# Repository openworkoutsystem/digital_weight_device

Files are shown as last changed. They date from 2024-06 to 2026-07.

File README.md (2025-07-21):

# Project Overview: Open-Source Smart Fitness

Open Workout System is an open-source community creating a high-fidelity smart health/fitness device dedicated to improving your fitness and health. Our primary goal is to develop cost-conscious, accessible, and safe workout systems that cater to a broad audience, from general fitness enthusiasts to individuals undergoing physical therapy. By leveraging open-source principles, we aim to foster a community of developers, fitness professionals, and users who can collaborate to continually improve and expand our solutions.

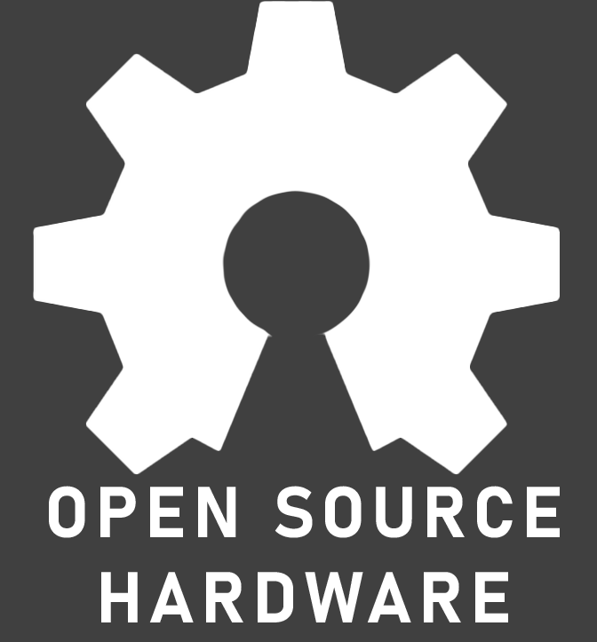
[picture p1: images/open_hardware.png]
Open Source Hardware

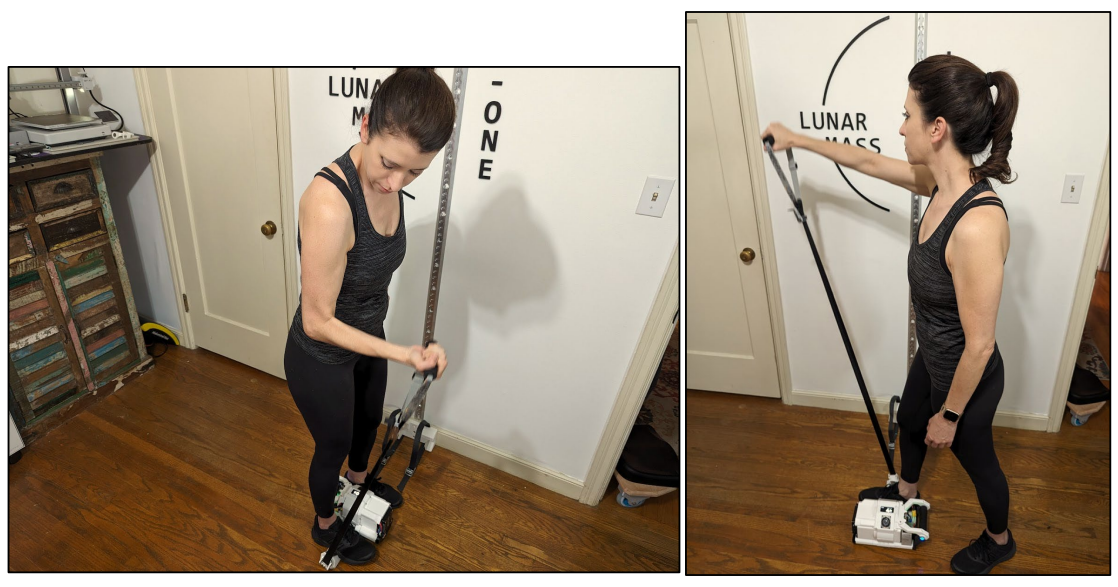
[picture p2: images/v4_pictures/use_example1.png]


### V4 Design Readme --> [V4 Design Readme](README_V4DESIGN.md)

### What's Different About This Project/Fitness Solution?

- Completely open source
- 11 lb device that can emulate up to 200 lb (exact specs in design)
- Fully wireless
- Use it anywhere: on the floor, with a door, wall, etc.
- Measures everything you want: power, speed, rep counter, timing
- Benchmarks your fitness
- Tracks your physical therapy progress
- Physical therapists will be able to design and monitor your progress for recovery (remotely and locally)
- Gamify your workout: We're excited to see how this device will be integrated in fun new ways to enhance your routine.

The ultra-compact BLDC motor-driven workout system is our core design focus, aimed at providing a comprehensive, safe, and affordable fitness solution. Traditional workout systems can be intimidating due to their size, complexity, and cost. Our system is ultra-compact and easy to use, ensuring it fits seamlessly into your life. The body-friendly strap enhances safety over a traditional cable system.

### Why Open Source?

As an open-source project, we believe in the power of community and collaboration. By making our designs, code, and documentation freely available, we enable others to contribute to the project, helping to accelerate innovation and bring high-quality fitness solutions to more people. Our commitment to open source ensures transparency, adaptability, and continuous improvement.

Hardware is hard. We want to provide access to a fantastic and safe fitness device for others to build their creative ideas on! Our philosophy is that we make you better, you make us better, and we're all better for it. We know, like us, there are others with great ideas on how to improve their daily routines and unique needs.

### Contribution

We welcome contributions to our project! Whether it's code, hardware designs, documentation, or testing, your input is valuable. To get started please join our Discord Community --> [Open Workout System Discord Server](https://discord.gg/DzmPTt3dUt)
For more information, questions, or collaboration inquiries, please contact us at [aaron.willey+ows@gmail.com].

### Safety and Accessibility

Safety is paramount in our design philosophy. Our Digital Weight Workout System includes features such as device movement sensing, dropped handle detection, and programmable safety limits to ensure a safe workout experience. The lower cost of entry allows a wider audience to access this advanced technology, promoting health and fitness across various demographics. Our goal is to provide a safer and more effective alternative to traditional free weights, reducing the risk of injury and making fitness accessible to all.

## Outline of Project Repositories

- **Digital Weight Device**: The main fitness device central to this project.
- **Applications that communicate with the digital weight**:
  - Web app (simple PWA interface for testing)
  - Mobile app - coming soon
  - Watch app - coming soon
- **Remote device**: Smart controller/remote for the digital weight.
- **Game demos**: Example integration of the device with different games for exploration of use ideas.

### Device Highlights

- **11 lb device**
- **Strength training up to 200 lb (400 lb 2X)**
- **Adaptive rowing and paddling modes**
- **Simple controls (mechanical and touch)**
- **Fully wireless**
- **Self-charging modes**
- **No installation required**
- **Safety features**:
  - Body-friendly strap (no cables)
  - Device movement sensing
  - Dropped handle detection
  - Programmable safety limits
  - Resistance only operation mode

### License

This project is licensed under the terms of the MIT license. See the [LICENSE](LICENSE) file for details.

## Digital Weight Workout System

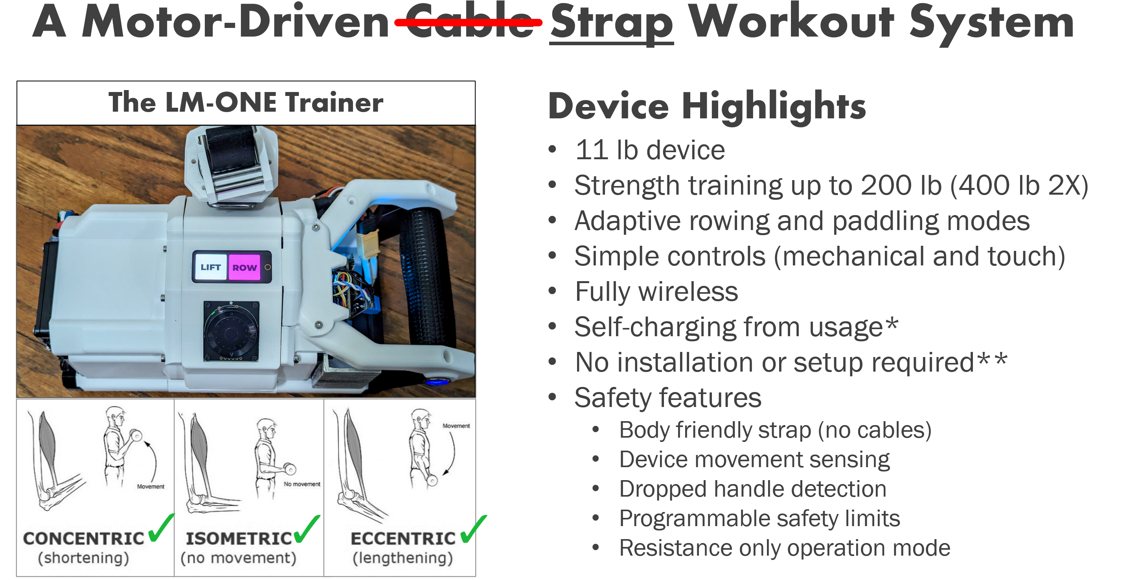
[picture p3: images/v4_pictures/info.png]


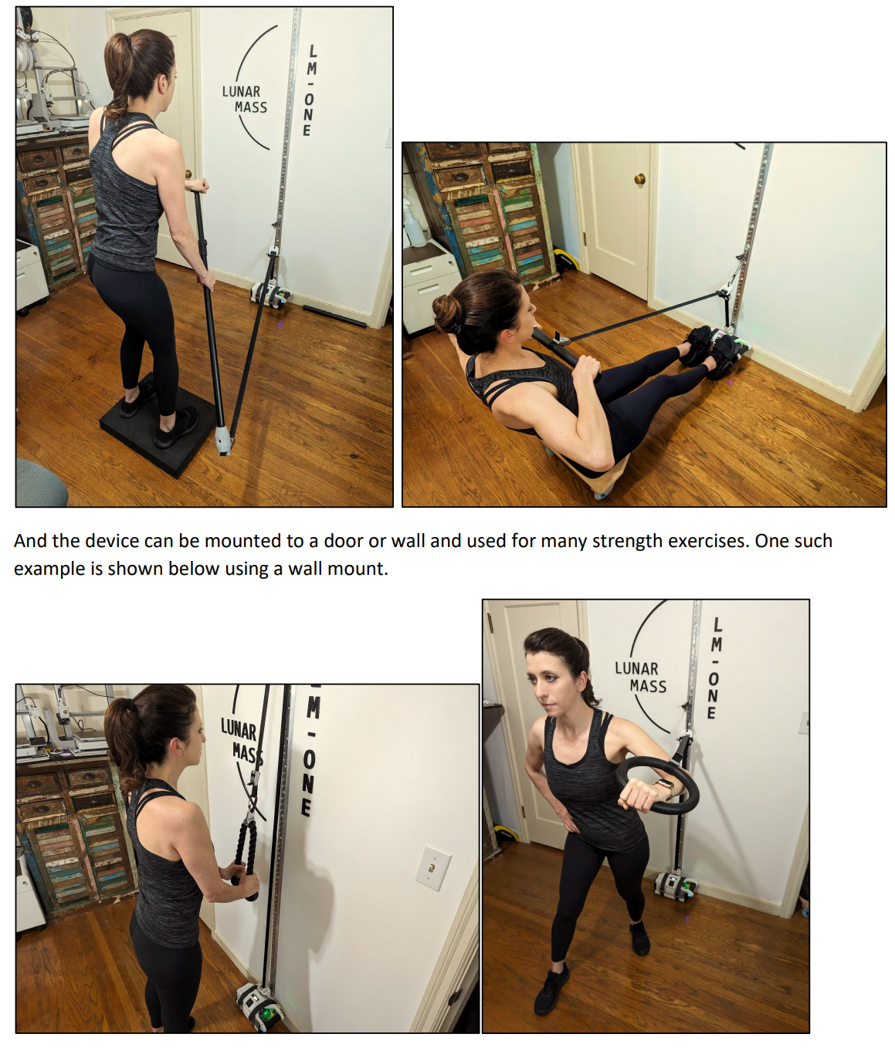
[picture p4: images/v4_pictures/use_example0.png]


Open Source Hardware

### Images and Features

#### v4 Pictures

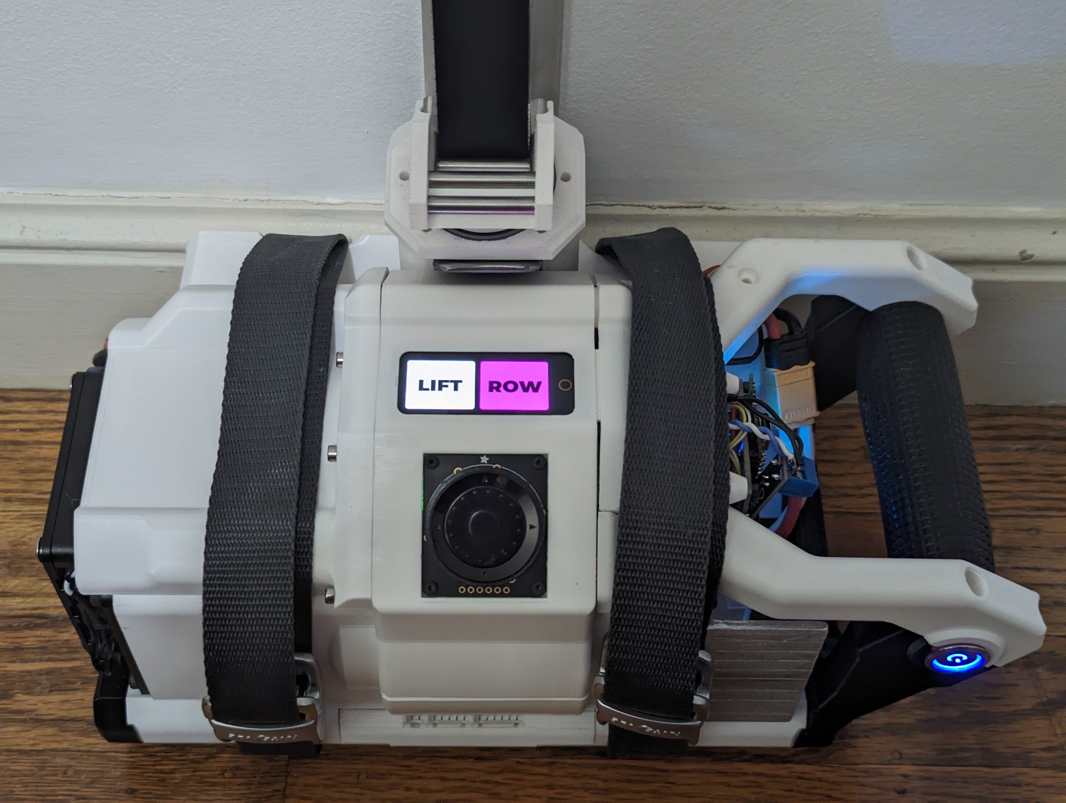
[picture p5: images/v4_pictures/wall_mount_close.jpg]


Open Source Hardware

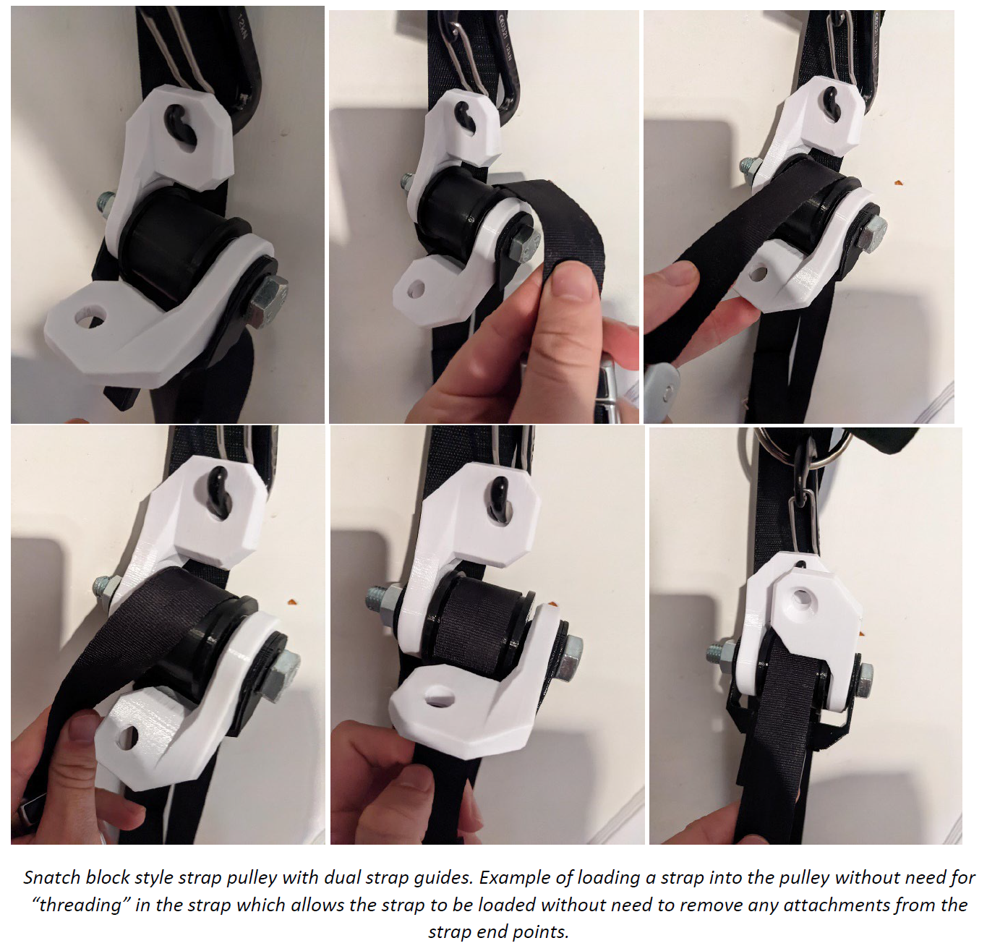
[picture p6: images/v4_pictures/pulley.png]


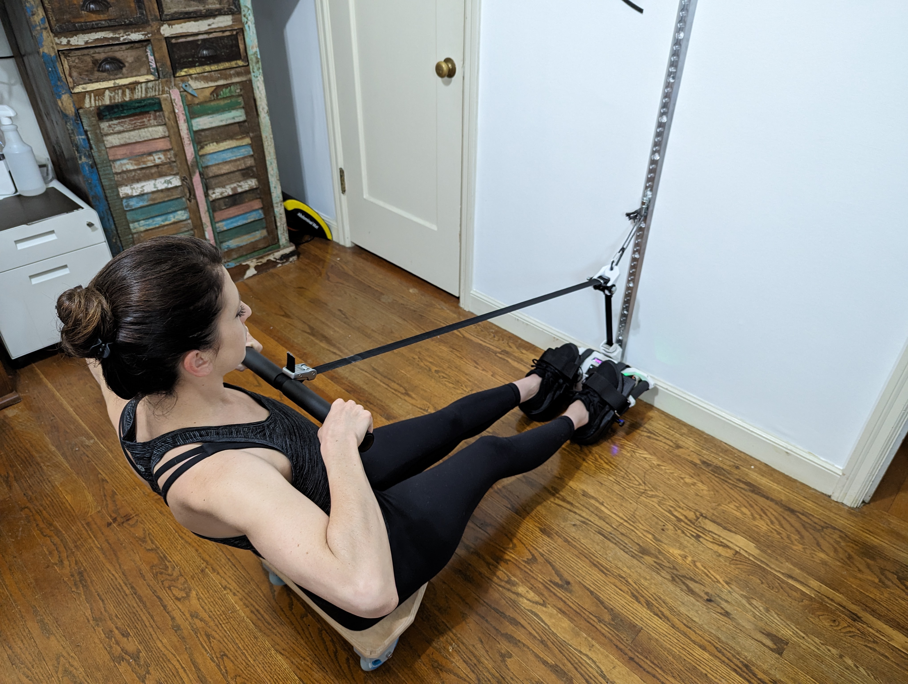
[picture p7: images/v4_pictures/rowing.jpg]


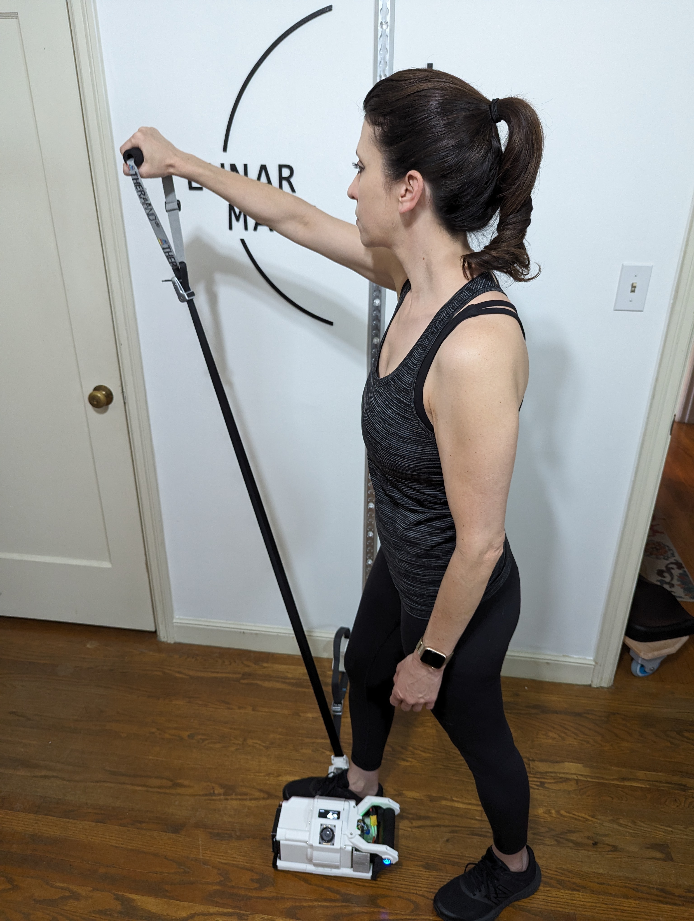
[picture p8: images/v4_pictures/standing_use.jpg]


Open Source Hardware

<!-- - ![Rowing](images/v4_pictures/rowing.jpg)
- ![Standing Use](images/v4_pictures/standing_use.jpg)
- ![Pulley](images/v4_pictures/pulley.png)
- ![Strength Tricep](images/v4_pictures/strength_tricep.jpg)
- ![Wall Mount Close](images/v4_pictures/wall_mount_close.jpg)
- ![Angle](images/v4_pictures/angle.jpg) -->

## Older v1_v2_v3 Pictures

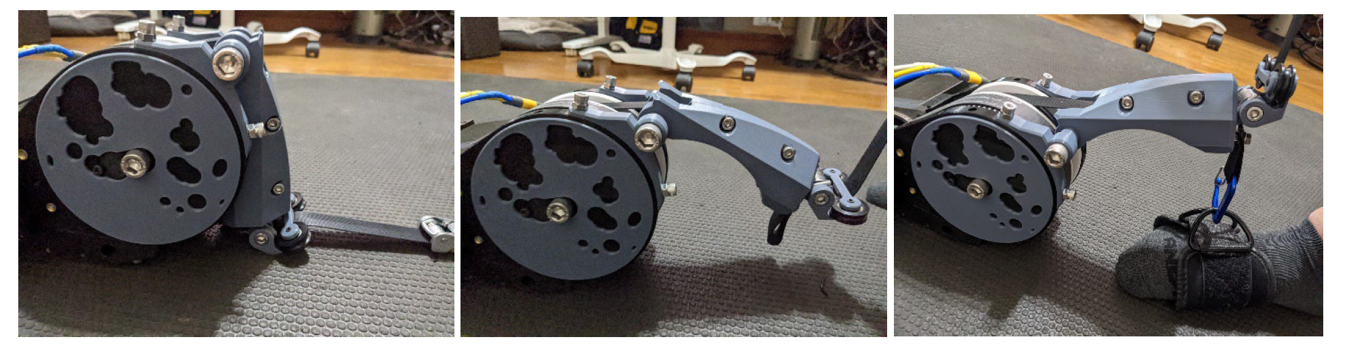
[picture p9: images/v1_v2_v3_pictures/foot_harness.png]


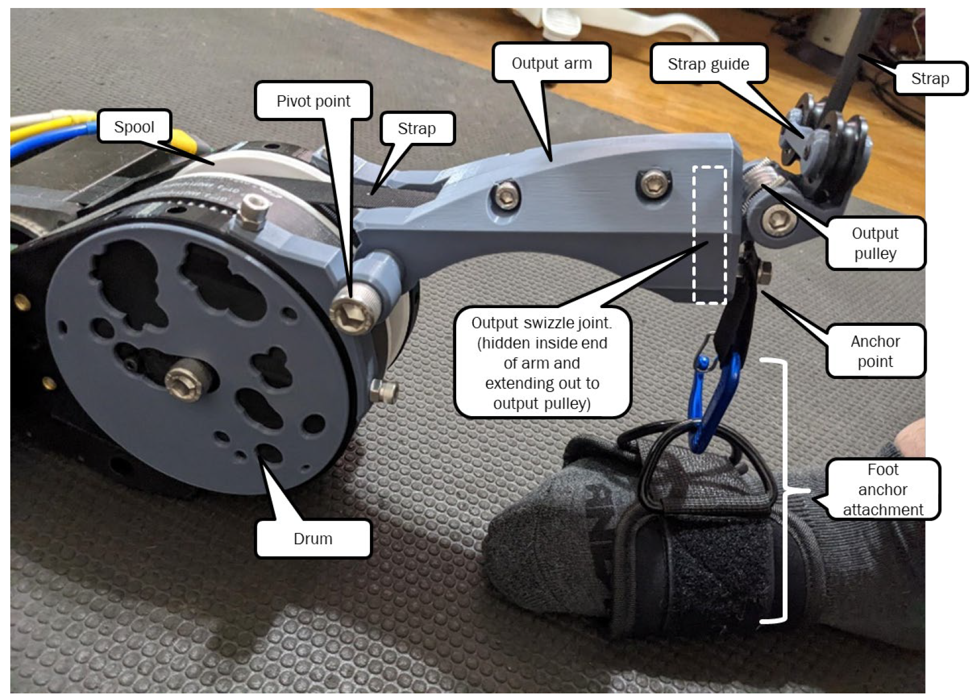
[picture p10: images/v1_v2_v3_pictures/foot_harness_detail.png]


<!-- - ![Foot Harness](images/v1_v2_v3_pictures/foot_harness.png)
- ![Detail](images/v1_v2_v3_pictures/foot_harness_detail.png) -->

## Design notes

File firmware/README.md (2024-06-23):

# Digital Weight Latest FW for V4

## Release Date

June 2024, as demonstrated at open sauce SF

## Overview

Two separate esp32 controllers. One as the master state machine for the device. The other only serves as a control input from the screen and controller knob.

## Odrive compiled firmware to be added

Note I have received soft confirmation from ODrive team that it is likely possible for us to obtain the source firmware and PCB files from their team. This could allow us to branch and create a cost optimized controller for our application and possibly directly use the odrive mcu for some of our higher-level control functions

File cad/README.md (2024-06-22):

# Digital Weight: V4 CAD

## Release Date

June 2024, as demonstrated at open sauce SF

## Introduction

CAD files to build V4

## Software and tools

- Autodesk inventor and Fusion 360
- Prusa MK3s
- Bambulab A1 (not mini)

## V4 Known Issues and Limitations - CAD related

- **Thermal Management**: Both motors tend to heat up too quickly, indicating a potential thermal issue.
- **Maintenance Challenges**:
  - Difficulty in removing motors with controllers for calibration.
  - Painful removal process for the handle when maintaining the odrive s1 controller.
- **Wiring**: Wire congestion around the device leads to pinched wires, reducing load carrying capacity.

## V4 Image Preview

V4 Render Angle
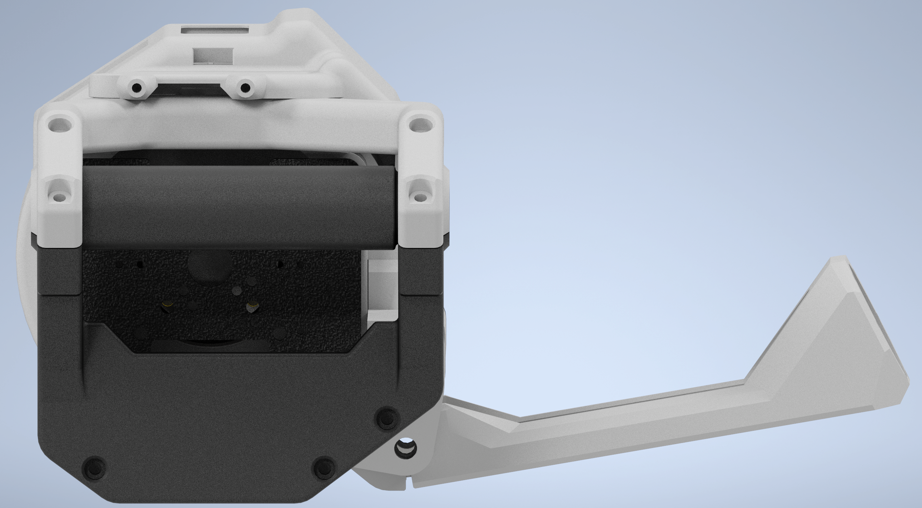
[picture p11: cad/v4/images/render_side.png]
V4 Render Angle

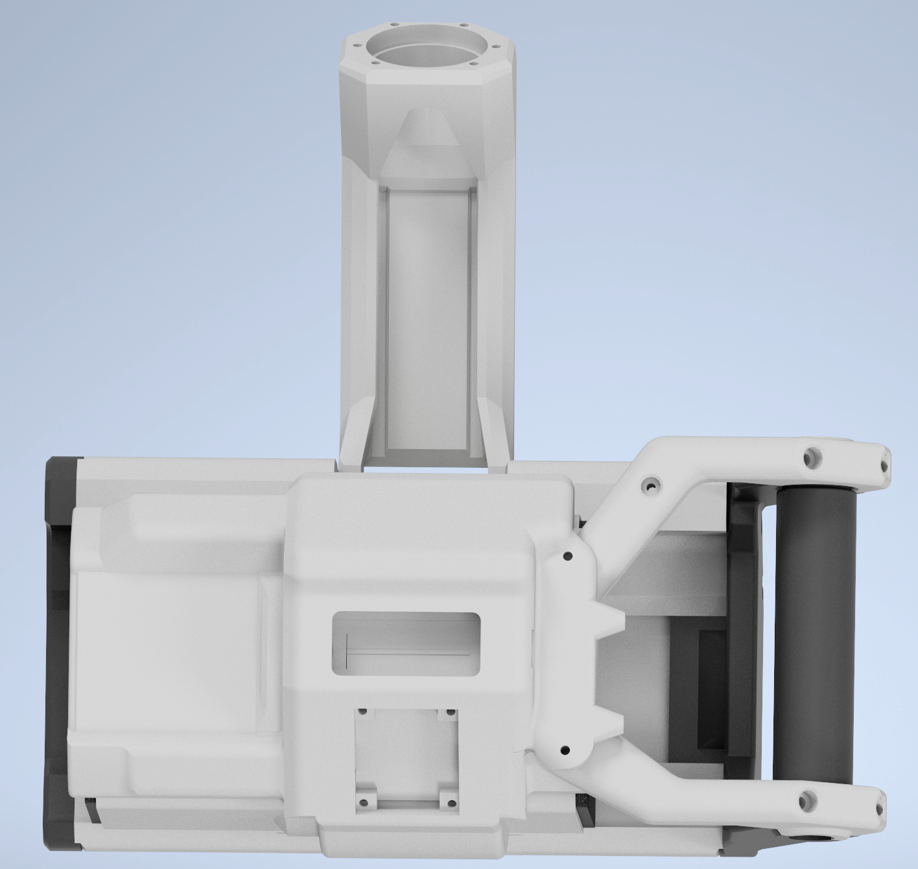
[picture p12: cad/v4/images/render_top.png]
V4 Render Angle


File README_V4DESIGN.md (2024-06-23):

# Digital Weight: Latest Version 4 (V4) - Overview

## Release Date

June 2024, as demonstrated at open sauce SF

## Introduction

The Digital Weight V4 represents the latest iteration of our open source fitness device. Working next towards V5 which will maintain the innovative and open spirit seen at Open Sauce. Version 4 introduces several enhancements and new features aimed at improving usability, safety, and performance.

## V4 BOM

[Bill of Materials](BOM.md)

## V4 Features

- **Dual Motor System**: Incorporates dual motors and controllers for enhanced performance.
- **Supports rowing**: The smaller motor and one-way clutch system allows this unit to rapidly respond with high speed while maintaining low inertia for safe use
- **Main Controller**: Utilizes an esp32s3 main controller board equipped with a CAN transceiver.
- **Design**: Features a flat output arm that can fold out flat onto the ground for versatile "free-floating" usage and easy mounting.
- **User Interface**: Equipped with a touch screen display and a physical rotary input knob for intuitive operation.
- **Strap**: Includes 6 meters (20 ft) of seatbelt webbing strap for secure handling.
- **Safety**: Integrated accelerometer/gyro for detecting device movement, enhancing safety.

## V4 Known Issues and Limitations

- **Thermal Management**: Both motors tend to heat up too quickly, indicating a potential thermal issue.
- **Maintenance Challenges**:
  - Difficulty in removing motors with controllers for calibration.
  - Painful removal process for the handle when maintaining the odrive s1 controller.
- **Startup Stability**: Power startup sequence with the touch screen is not stable, especially when the screen powers up before the device.
- **Power Distribution**: Issues with hijacking power for the LCD and main controller from the odrive S1.
- **Wiring**: Wire congestion around the device leads to pinched wires, reducing load carrying capacity.
- **Battery**: The current battery setup lacks an on-board BMS, balancer, power management, or thermal monitoring.
- **Mounting**: The existing frame mounting requires straps placed around the unit, necessitating a better solution.
- **Firmware**: The firmware has been rewritten from scratch for V4, resulting in the absence of some base features critical for safety and convenience.
- **General safety**: The device has not yet fully enabled all watchdog, movement monitoring, and control limitations to ensure the safety of the user. Test and use with caution.

## V4 Image Preview

V4 Render Angle

## V5 Next Steps

Squash bugs and known limitations

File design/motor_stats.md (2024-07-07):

# BLDC Motor Characteristics and Calculated Stats

## Motor from ODrive Robotics M8325s - 100kv  
[Link to Motor](https://shop.odriverobotics.com/products/m8325s)

| Characteristic | Value |
|---|---|
| Weight | 841 grams |
| Gear Ratio | 5.5 |
| KV Rating | 100 RPM/V |
| Max Current | 60.0 A |
| Max Voltage | 60 V |
| Phase Resistance | 44 ohms |
| Price | $120 |
| Max Continuous Current | 10.0 A |
| Rated Torque at Max Continuous Current | 1.10 Nm |
| Peak Torque at Max Current | 6.60 Nm |
| No Load RPM | 4320.00 RPM |
| Continuous Linear Force | 27.50 N (6.18 lb) |
| Peak Linear Force | 165.00 N (37.09 lb) |
| Linear Speed | 18.10 m/s (59.37 ft/s) |
| Rated Torque at Max Continuous Current with Gear | 6.05 Nm |
| Peak Torque at Max Current with Gear | 36.30 Nm |
| No Load RPM with Gear | 785.45 RPM |
| Continuous Linear Force with Gear | 151.25 N (34.00 lb) |
| Peak Linear Force with Gear | 907.50 N (204.01 lb) |
| Linear Speed with Gear | 3.29 m/s (10.79 ft/s) |

## Motor from Cube Mars RO100 Frameless kv55  
[Link to Motor](https://www.cubemars.com/goods-1159-RO100.html)

| Characteristic | Value |
|---|---|
| Weight | 750 grams |
| Gear Ratio | 5.5 |
| KV Rating | 55 RPM/V |
| Max Current | 60.0 A |
| Max Voltage | 48 V |
| Phase Resistance | 65 ohms |
| Price | $170 |
| Max Continuous Current | 20.0 A |
| Rated Torque at Max Continuous Current | 4.00 Nm |
| Peak Torque at Max Current | 12.00 Nm |
| No Load RPM | 2376.00 RPM |
| Continuous Linear Force | 100.00 N (22.48 lb) |
| Peak Linear Force | 300.00 N (67.44 lb) |
| Linear Speed | 9.95 m/s (32.65 ft/s) |
| Rated Torque at Max Continuous Current with Gear | 22.00 Nm |
| Peak Torque at Max Current with Gear | 66.00 Nm |
| No Load RPM with Gear | 432.00 RPM |
| Continuous Linear Force with Gear | 550.00 N (123.64 lb) |
| Peak Linear Force with Gear | 1650.00 N (370.93 lb) |
| Linear Speed with Gear | 1.81 m/s (5.94 ft/s) |

## Motor from Cube Mars RI100 Frameless kv105 
[Link to Motor](https://www.cubemars.com/goods-859-RI100.html)

| Characteristic | Value |
|---|---|
| Weight | 600 grams |
| Gear Ratio | 5.5 |
| KV Rating | 105 RPM/V |
| Max Current | 47.6 A |
| Max Voltage | 48 V |
| Phase Resistance | 65 ohms |
| Price | $140 |
| Max Continuous Current | 16.9 A |
| Rated Torque at Max Continuous Current | 1.77 Nm |
| Peak Torque at Max Current | 4.99 Nm |
| No Load RPM | 4536.00 RPM |
| Continuous Linear Force | 44.26 N (9.95 lb) |
| Peak Linear Force | 124.67 N (28.03 lb) |
| Linear Speed | 19.00 m/s (62.34 ft/s) |
| Rated Torque at Max Continuous Current with Gear | 9.74 Nm |
| Peak Torque at Max Current with Gear | 27.43 Nm |
| No Load RPM with Gear | 824.73 RPM |
| Continuous Linear Force with Gear | 243.44 N (54.73 lb) |
| Peak Linear Force with Gear | 685.67 N (154.14 lb) |
| Linear Speed with Gear | 3.45 m/s (11.33 ft/s) |

## Motor from Custom                          
[Link to Motor](nan)

| Characteristic | Value |
|---|---|
| Weight | 1200 grams |
| Gear Ratio | 1.0 |
| KV Rating | 20 RPM/V |
| Max Current | 100.0 A |
| Max Voltage | 48 V |
| Phase Resistance | 65 ohms |
| Price | $140 |
| Max Continuous Current | 40.0 A |
| Rated Torque at Max Continuous Current | 22.00 Nm |
| Peak Torque at Max Current | 55.00 Nm |
| No Load RPM | 864.00 RPM |
| Continuous Linear Force | 550.00 N (123.64 lb) |
| Peak Linear Force | 1375.00 N (309.11 lb) |
| Linear Speed | 3.62 m/s (11.87 ft/s) |
| Rated Torque at Max Continuous Current with Gear | 22.00 Nm |
| Peak Torque at Max Current with Gear | 55.00 Nm |
| No Load RPM with Gear | 864.00 RPM |
| Continuous Linear Force with Gear | 550.00 N (123.64 lb) |
| Peak Linear Force with Gear | 1375.00 N (309.11 lb) |
| Linear Speed with Gear | 3.62 m/s (11.87 ft/s) |

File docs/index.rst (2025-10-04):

Welcome to Open Workout System API Documentation!
=================================================

The Open Workout System provides a digital weight device for precise weight measurements in fitness and research applications.

This documentation covers the firmware APIs for the ESP32-based digital weight device.

.. toctree::
   :maxdepth: 2
   :caption: Contents:

   api

Indices and tables
==================

* :ref:`genindex`
* :ref:`modindex`
* :ref:`search`

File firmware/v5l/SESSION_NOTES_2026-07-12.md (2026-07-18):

# Session Notes — Weight System Overhaul (2026-07-11 → 2026-07-12)

Restore-context document for the v5l firmware work session (Claude Code).
Covers both boards: `esp32s3_lillygo_amoled` (screen) and `esp32s3_main`
(motor controller). Everything below is BUILT and bench-verified except
where marked TODO.

---

## System architecture (as of end of session)

```
Screen (T-Display S3 AMOLED 1.91")          Main (Seeed XIAO ESP32S3)         ODrive S1 (fw 0.6.12)
┌─────────────────────────────┐   I2C    ┌──────────────────────────┐   CAN   ┌──────────────────┐
│ touch numpad sets weight    │ ───────► │ cmd queue → weight gate  │ ──────► │ M1, velocity mode│
│ red ZERO zone (left 30%)    │  0x08    │ → zone taper → drop-catch│  250k   │ setpoint -20 t/s │
│ 1 Hz status poll (checksum) │ ◄─────── │ → torque_soft_min writes │         │ torque_soft_min  │
│ ack/retry on commands       │          │ states: ACTIVE/RECOIL/   │         │ = the force      │
└─────────────────────────────┘          │         SLEEP            │         └──────────────────┘
```

**Force rendering ("the way"):** ODrive runs velocity control toward a
permanently unreachable reel-in setpoint (−20 turns/s), so it sits in
torque saturation and `axis0.config.torque_soft_min` IS the rendered
force. Written over CAN RxSdo (cmd 0x04) at **endpoint 304**;
`torque_soft_max` = **305**, streamed constant −/+0.5 Nm (motor must never
push toward the user). Endpoint IDs verified against
`firmware/v5l/odrive_s1/flat_endpoints.json` (fw 0.6.12) — **IDs are
firmware-version-specific and fail SILENTLY if stale**; re-check that file
after any ODrive fw update (`cal {"ep_min":<id>}` retargets live; the 1 Hz
TxSdo readback probe prints `[wg] ODrive readback ep=... val=...` when the
ID is right). Fallback path: Set_Limits (0x00F) current_limit with
`amps_per_nm` (cal `use_ep:false`).

**Calibration anchor (bench-measured):** 0.5 Nm ≈ 1 lbf at the handle
(≈2 lbf/Nm, near-direct drive, large spool). Stroke is multiple turns
(span telemetry in `[wg]` line measures it). Torque matrix is a pure
LINEAR law: torque = 0.5 Nm × screen units, NO plateau — upper rows exceed
motor ability on purpose (torque_soft_min is a bound, not a setpoint; the
ODrive saturates at max_current × Kt and force tops out gracefully).
Ceiling chain: `max_current` (20 A) × Kt → ODrive motor config → thermals.

## Safety / behavior layers (main board, MotorControl.cpp)

Applied in order: weight gate → RECOIL override → zone taper → drop-catch.
All share the 0.5 Nm (~1 lbf) floor and one philosophy: **force is only
ever restored by pulling into it.**

1. **Weight gate (pull-to-confirm increases):** new weight arms; force
   ramps old→new over `delta_x` (0.22) of pull after `deadband` (0.03),
   latches after `delta_y` (0.06) more; backing out > `cancel` (0.08)
   makes the ramp descend-only and CANCELS (screen snaps back via sync).
   Progress <10% just re-arms (jitter tolerance). Decreases apply
   IMMEDIATELY with a 75 units/s time slew — never gated. 0 = immediate.
2. **Machine states:** ACTIVE (weight set) / RECOIL (0 lb = 0.5 Nm
   self-stow at `recoil_vel` 2 turns/s) / SLEEP (axis idle). Sleep entry:
   parked within the home zone AND position still (within `wake_d` 0.05
   turns — position-window, NOT velocity: encoder velocity noise is ±0.2
   at rest) for `sleep_s` 10 s. Wake: movement > `wake_d` → closed loop in
   low/slow profile within ms; the zone taper re-delivers the latched
   weight with travel. Boot state = SLEEP. Latched weight survives sleep.
3. **Home + zone taper:** home = running min of pull position
   (bounce-filtered: only updates when |v| < 0.5). Within `zone` (0.75
   turns) of home, the force's excess above the floor scales linearly with
   distance — pinch safety at the dock, per-rep soft pickup, wake guard.
   Scales the REQUEST (no fixed ceiling → no step at the boundary).
4. **Drop-catch (anti-runaway):** reel-in faster than `drop_vmin` (2
   turns/s) sheds excess force linearly, floor-only at `drop_vmax` (8);
   one-way ratchet (no resurge on slow-down); restored linearly over
   `drop_restore` (0.3) turns of outward travel. Pull-out never limited.
   Does not touch the gate/screen — output-only suppression.

## Screen (apps/ows/)

- **Numpad** (`weight_numpad.cpp/h` — OUTSIDE `src/` so SquareLine
  re-exports can't clobber it): tap the weight number → modal 0–150 pad.
- **Red ZERO zone**: left 160 px of StrengthScreen, fires on PRESS →
  `handleMainScreenEvent(0)` → recoil. Created in code post-`ui_init()`.
- **Fonts**: weight value = RowFont2 (140 px, was 230 and ran under the
  X); "lb" = montserrat 32; static "43%" placeholder hidden.
- **Status link**: `SharedStateData` 24 bytes, seq + additive checksum
  (seed 0xA5) in old tail padding. Screen polls 1 Hz, drains stale bytes
  first, REJECTS bad checksum (counted on serial). Main always answers
  (last-good snapshot on mutex miss — empty responses were the NaN
  voltage bug: master clocked 0xFF filler = NaN float).
- **Command ack/retry**: weight sends tracked until main reports them
  (pending or active); unacked after 1 s → resend, ×3, then adopt main's
  truth. Distinguishes lost-command (resend) from user-cancel (snap back).
- **⚠ struct lockstep**: `SharedStateData` must stay byte-identical in
  `ows.ino` and `I2CCommunication.h`; flash BOTH boards when it changes.
- Splash: full-screen logo (240×536, byte-swapped RGB565 via
  `convert_logo.py`), drawn post-DISPON, redrawn after deferred init
  (cold-boot fix), dim boot + ramp. LilyGo SPI has NO lock — pixel writes
  from the LVGL/main task only.

## Live tuning — WiFi `cal` command (WS + HTTP, RAM-only, resets on boot)

```json
{"command":"cal",
 "force_scale":1.0, "zero_m1":0.1,
 "row":3, "values":[200,8,-10.2,0,-10.2,0],
 "delta_x":0.22, "delta_y":0.06, "deadband":0.03, "cancel":0.08,
 "pull_sign":1, "amps_per_nm":12, "vel_limit":25, "max_current":20,
 "ep_min":304, "use_ep":true,
 "zone":0.75, "recoil_tq":0.5, "recoil_vel":2, "soft_max":0.5,
 "sleep_s":10, "wake_d":0.05,
 "drop_vmin":2, "drop_vmax":8, "drop_restore":0.3,
 "test_torque":0.5, "debug":true}
```
Omitted keys unchanged. `test_torque`: constant reel-in Nm for 10 s
(clamp ±3), for Nm→felt-lbf mapping. Bake tuned values into the source
defaults once bench-final.

## Telemetry (`[wg]` serial line, 4 Hz, `debug:false` to silence)

`st` gate state (0 inactive/1 armed/2 ramping/3 cancelling) · `ms` machine
state (0 sleep/1 recoil/2 active) · `act/pend` weights · `tgt` N ·
`Tq` sent Nm · `d` dist from home · `drop` shed fraction · `pos/v` ·
`mode` (1 = streaming) · `span` min/max pos since boot (stroke measure).
Plus 1 Hz `ODrive readback ep=0x0130 val=...` (write verification).

## Hard-won debugging lessons (do not relearn)

- ODrive CAN endpoint IDs are fw-specific; wrong IDs are silent no-ops —
  weeks of "constants change nothing" came from 0x0101 vs 304. Verify via
  readback, never assume.
- `createCANMessage` zeroes payloads now — RxSdo byte 3 (reserved, must
  be 0) was uninitialized stack garbage.
- Empty I2C slave responses → master reads 0xFF → NaN floats. Always
  answer; always checksum.
- ESP32 encoder velocity jitters ±0.2 turns/s at rest — never threshold
  raw velocity for stillness; use position windows.
- Fire-and-forget commands + truth-sync = phantom reverts; ack everything.
- RM67162: RAM writes before DISPON are dropped; panel needs ~100 ms after
  cold power-on; brightness 0x51 latches only after DISPON.

## Open TODOs

- **Units quirk (deliberate, unreconciled):** screen "lb" number is
  treated as kg internally (×9.81 → N); WiFi converts lb→kg first. Same
  number, different force per path. Reconcile in a units pass someday.
- Bake bench-tuned cal values into source defaults (they reset on boot).
- Product max-weight intake clamp once the motor ceiling is measured
  (screen WEIGHT_MAX=150 + mirror on WiFi paths).
- Eccentric bias: matrix pull-in vs pull-out columns are symmetric now;
  add via row edits when feel work resumes.
- `processI2CData()` legacy SET_DEBUG mode-toggle path is dead code.
- Hardware: bulk cap on 5V rail still the real fix for cold-boot margin.
- `weight_max`, damping, dynamic feedback fields in I2C cmd: sent but
  unused.

## Build / flash

- Screen: `esp32s3_lillygo_amoled/` → `pio run -e T-Display-AMOLED -t upload` (COM3)
- Main: `esp32s3_main/` → `pio run -e seeed_xiao_esp32s3 -t upload`
- PlatformIO at `%USERPROFILE%\.platformio\penv\Scripts\platformio.exe`

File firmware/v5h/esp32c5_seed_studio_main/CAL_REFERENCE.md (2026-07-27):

# `cal` command reference — v5h C5 main board

Send as JSON to the C5, keys freely combinable, omitted keys unchanged:

```powershell
Invoke-RestMethod -Uri http://192.168.1.140/command -Method Post -Body '{"command":"cal","recoil_tq":0.8,"recoil_vel":10}'
```

(or the same JSON over WebSocket :81, or browser F12 console via `fetch`).

**All changes are RAM-only** — instant effect, reverted by reboot. Bake keepers
into `MotorControl.cpp` defaults. Out-of-range values are silently ignored
(each setter clamps; ranges below). Units: revolutions / rev/s / N·m; on this
drivetrain **1 N·m ≈ 5 lbf at the handle** and a full stroke ≈ 5 revs.

## Strength feel
| key | default | range | meaning |
|---|---|---|---|
| `force_scale` | 0.40 | (0..1] | screen-lb → torque anchor, MIDPOINT-anchored: = 0.32 (pull-measured) × (1+K_TRUE 0.25). Holds/slow motion read the set weight; independent of `fric_k` — do NOT re-anchor when tuning it |
| `fric_k` | 0.17 | [0..0.5] | directional friction comp: boosts lowering / trims pulling by ±k (≈70% of the measured 0.25 capstan loss — never exceed measured; overcomp = negative damping) |
| `fric_band` | 0.6 | rev/s | pull speed at which the comp blend saturates |
| `zero_m1` | 0.1 | [0..1] | keep-taut floor torque (N·m) at ~0 target force |
| `recoil_tq` | 0.8 | [0..2] | 0 lb self-stow pull, N·m (~4 lbf) |
| `recoil_vel` | 8 | (0..50] | 0 lb stow speed, rev/s (slows to ~2 near the dock automatically) |
| `zone` | 1.0 | (0..10] | dock zone (revs): force tapers + speed drops inside it |
| `sleep_s` | 10 | (0..3600] | parked-and-still seconds before the axis sleeps |
| `sleep_zone` | 0.15 | (0..2] | revs from home within which sleep is ALLOWED (docked = nobody holding); a still hold beyond it never sleeps |
| `wake_d` | 0.25 | (0..1] | revs of strap movement that wake from sleep |
| `soft_max` | 0.5 | [0..2] | legacy ODrive push-out bound — **inert on moteus**, kept for compat |
| `con_pct` | 0 | [0..100] | concentric-only unloading: % of force removed when not actively pulling out (also settable from the strength screen's CON label) |
| `con_lo` / `con_hi` | 0.3 / 1.5 | rev/s | pull-velocity band over which force blends back in |

## Weight-update gate (pull-to-confirm, revs of travel)
| key | default | meaning |
|---|---|---|
| `delta_x` | 1.1 | ramp length: force climbs old→new over this much pull |
| `delta_y` | 0.3 | extra hold past the ramp before the new weight latches |
| `deadband` | 0.15 | pull needed to start the ramp after arming |
| `cancel` | 0.4 | backtrack that cancels a pending increase |
| `pull_sign` | +1 | ±1: flip if position decreases when pulling out |

## Drop-catch (anti-runaway)
| key | default | meaning |
|---|---|---|
| `drop_vmin` | 6 | reel-in rev/s where force shedding starts |
| `drop_vmax` | 15 | reel-in rev/s where only the floor remains (> vmin) |
| `drop_restore` | 1.5 | revs of pull-out to fully restore shed force |

## Row model
| key | default | range | meaning |
|---|---|---|---|
| `row_kc` | 2.5 | (0..100] | catch stiffness: N·m per rev/s of overspeed at gear 5 |
| `row_inertia` | 5 | (0..100] | virtual wheel inertia — bigger = longer glide, steadier drive force |
| `row_drag_base` | 0.15 | (0..10] | decay coefficient the 1-10 screen damper scales |
| `row_return` | 0.6 | [0..2] | recovery tension N·m — also the strap's chase muscle (they are the same thing in this scheme) |
| `row_max` | 10 | (0..100] | ceiling on rendered row force |
| `row_zone` | 0.5 | (0..10] | pinch-only dock taper (revs) in row mode |

(Gear and drag are user settings — tap the numbers on the row screen.)

## Torque matrix (advanced)
`{"row":N,"values":[force_N, vel_delta, -Fn, -Fm, +Fn, +Fm]}` — hot-edit row
N (0-5) of the force→torque lookup. Row 0 is the zero/keep-taut row.

## Utility / probes
| key | default | meaning |
|---|---|---|
| `test_torque` | — | stream a constant reel-in torque (N·m, clamp ±3) for 10 s — the felt-force calibration probe. 0 cancels. Needs strength mode active. |
| `debug` | true | `[wg]`/`[row]` 4 Hz serial telemetry on/off |
| `can_quiet` | false | mute ALL CAN TX (mandatory during moteus calibration/tview driving) |
| `brs` | true | CAN-FD 5 Mbps data phase; false = whole bus at 1 Mbps (signal-integrity fallback) |
| `reel_in_vel` | 20 | chase velocity setpoint magnitude, rev/s (rarely touched) |
| `vel_limit` | 25 | away-from-dock velocity ceiling, rev/s (rarely touched) |

## Recipes
```json
{"command":"cal","test_torque":1.0}                       // feel exactly 1 Nm for 10 s (luggage-scale it)
{"command":"cal","force_scale":0.38}                      // trim screen-lb accuracy
{"command":"cal","recoil_tq":0.8,"recoil_vel":10}         // stronger, faster 0 lb stow
{"command":"cal","row_return":1.5,"row_kc":3.0}           // firmer row recovery + catch
{"command":"cal","delta_x":1.5,"deadband":0.2}            // longer pull-to-confirm ramp
{"command":"cal","can_quiet":true}                        // silence C5 for bench work
```

The response echoes `force_scale`, `zero_m1`, `brs`, `can_quiet` as a landing
confirmation.

---

# Full command vocabulary (beyond `cal`)

Same transport for all: HTTP `POST /command` or WebSocket :81.

| command | body | effect |
|---|---|---|
| `strength` | `{"command":"strength","weight_lbs":10}` (or `weight_kg`) | set a weight — identical path to the screen numpad, pull-to-confirm gate applies |
| `idle` | `{"command":"idle"}` | weight 0 / off (recoil-stow, then sleep) — also exits row mode |
| `row` | `{"command":"row","type":"on","gear":5,"drag":5}` (`"off"` to leave) | row mode from the app side, same as entering/leaving the row screen |
| `cal` | see tables above | live tuning, incl. `can_quiet` (CAN mute) and `brs` |
| `pulse` | `{"command":"pulse","type":"on","duration":0,"strength":50,"frequency":8}` | sine force modulation on top of the set weight (haptic texture) |
| `force` | `{"command":"force","type":"constant","strength":100,...}` | force profile: `off` / `constant` (percent of set weight) / `linear` (ramps with position) |
| `detent` | accepted | **currently inert** — the detent stage is commented out of the force pipeline |
| `mode` | `{"command":"mode","type":"strength"}` | bookkeeping label only (status/metrics reporting) |

Read-only endpoints:
- `GET /metrics` — full JSON: position, velocity, force, voltage, current, IMU, `row_watts`, `row_spm`, latency timestamps
- `GET /health` — `{"status":"OK","uptime":...}`
- WebSocket :81 also **pushes** a metrics frame every ~400 ms — subscribe and you get live telemetry with no polling.

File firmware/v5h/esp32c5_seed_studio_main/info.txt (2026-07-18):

Using SparkFun Micro 6DoF IMU Breakout - BMI270... need to connect it via i2c qwiic connector...

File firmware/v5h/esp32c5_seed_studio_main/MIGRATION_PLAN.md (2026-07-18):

# v5h Main Board Migration Plan — XIAO ESP32-S3 → XIAO ESP32-C5, ODrive S1 → moteus-x1

Date: 2026-07-12. Status as of 2026-07-17: **BRING-UP COMPLETE — working
machine.** Strength and row modes live on the new architecture; see the
session log at the bottom of this file for the full state of the world.
Build from native PowerShell/cmd — NOT Git Bash: ESP-IDF's tool installer
aborts in MSys environments ("MSys/Mingw is not supported").

Why: the ESP32-C5 has native CAN-FD (2× TWAI-FD controllers, CTU CAN FD IP), which the
mjbots moteus-x1 requires (CAN-FD only, 1 Mbps arbitration / 5 Mbps data, not configurable
on the controller). Transceiver: Adafruit CAN Pal (TJA1051T/3) — rated for 5 Mbit/s CAN-FD
data phase per the current NXP datasheet (Rev. 8/9, 2016+; the "2 Mbit/s" figure is from
pre-2016 datasheet revisions of the same silicon). mjbots themselves recommend TJA1051T/3.

---

## 1. Pin map (Seeed XIAO ESP32-C5)

Physical pads are kept identical to the current XIAO ESP32-S3 harness wherever possible.

| XIAO pad | C5 GPIO | Function | Connects to | Old S3 GPIO (same pad) |
|---|---|---|---|---|
| **D3**  | GPIO7  | TWAI-FD RX | CAN Pal `RX` | GPIO4 (CAN RX) |
| **D8**  | GPIO8  | TWAI-FD TX | CAN Pal `TX` | GPIO7 (CAN TX) |
| **D4**  | GPIO23 | I2C0 SDA — **slave @ addr 8** | Display board SDA (LilyGo GPIO43) | GPIO5 (SDA) |
| **D5**  | GPIO24 | I2C0 SCL — **slave @ addr 8** | Display board SCL (LilyGo GPIO44) | GPIO6 (SCL) |
| **rear pad MTMS** | GPIO2 | LP-I2C SDA — master | BMI270 Qwiic SDA (blue) | (new) |
| **rear pad MTDI** | GPIO3 | LP-I2C SCL — master | BMI270 Qwiic SCL (yellow) | (new) |
| rear pad 3V3 | — | 3.3 V | BMI270 Qwiic 3V3 (red) | |
| rear pad GND | — | GND | BMI270 Qwiic GND (black) | |
| 3V3-OUT (front) | — | 3.3 V | CAN Pal `Vcc` | |
| GND (front) | — | GND | CAN Pal `GND` + display GND | |

Free for future use: D0 (GPIO1, ADC1_CH0), D1 (GPIO0), D2 (GPIO25), D6 (GPIO11/U0TX),
D7 (GPIO12/U0RX), D9 (GPIO9), D10 (GPIO10). Board-reserved: GPIO27 user LED (active-low),
GPIO28 BOOT button, GPIO6 battery ADC + GPIO26 battery-sense enable, GPIO13/14 USB.

### Why these pins

- **CAN on D3/D8 (GPIO7/GPIO8):** same pads as the old harness. TWAI-FD routes to any GPIO
  via the GPIO matrix — no dedicated pins. GPIO8 is *not* a strapping pin on the C5.
  GPIO7 *is* a strapping pin (JTAG signal source, no internal pulls), but: (a) with stock
  eFuses the strap is ignored (USB-Serial-JTAG stays default), and (b) the TJA1051's RXD
  output is push-pull and idles high (bus recessive), which gives the pin a firm, defined
  level through reset — it satisfies the datasheet's "must not float" requirement. Do not
  ever move CAN RX to GPIO28 (BOOT): a dominant bit during reset would enter download mode.
- **Display link on D4/D5 (GPIO23/24):** the C5's only high-performance I2C controller
  (I2C0) stays in slave mode at address 8, so the display board firmware, protocol, and
  harness are 100 % unchanged. These are also the C5's default `Wire` pins.
- **IMU on GPIO2/GPIO3 (rear MTMS/MTDI pads):** the C5 has **only one HP I2C controller**
  (datasheet §4.2.1.3) — the S3's "slave-to-display + master-to-IMU on two hardware buses"
  design cannot map 1:1. The LP (low-power) I2C controller is a hardware master fixed to
  LP_GPIO2/3 = GPIO2/3, which on the XIAO exist only as the rear JTAG through-hole pads.
  Conveniently, 3V3 and GND pads sit in the same rear cluster, so the whole Qwiic pigtail
  lands in one place. GPIO2/3 are strapping pins, but the BMI270's 2.2 kΩ pull-ups holding
  them high at boot is harmless (GPIO2: JTAG-related, GPIO3: SDIO clock-edge — neither used).
  - Software path A (try first): `Wire1` — on the C5 Arduino core it maps to the LP-I2C.
  - Software path B: ESP-IDF `i2c_new_master_bus()` with `.i2c_port = LP_I2C_NUM_0`,
    `.clk_source = LP_I2C_SCLK_DEFAULT`, wired into the Bosch bmi2 read/write fptrs.
  - Software path C (last resort, **same wiring**): bit-bang I2C on GPIO2/3 — they are
    normal GPIOs after boot, so the harness is robust to any software outcome.
  - **No-rear-solder alternative (decided against, but valid):** bit-bang I2C on front
    pads D9/GPIO9 (SCL) + D10/GPIO10 (SDA) — the same pads the S3 harness used for the
    IMU. Master-side bit-bang tolerates preemption (transactions stretch, never corrupt),
    so at low task priority it can't disturb the control loop; ~4 % CPU at 400 kHz /
    100 Hz reads. Requires driving the Bosch bmi2 API with custom read/write fptrs
    (SparkFun's class wants a `TwoWire&`). Rear pads were chosen because the hardware
    LP-I2C costs zero CPU and the soldered wiring covers every software fallback.
  - End-state option: when the display-link protocol rework happens (planned), flip the
    C5 to bus master and put display + BMI270 on the one HP I2C0 bus; the LP bus then
    goes away. Not done now to avoid changing two firmwares mid-migration.
  - Note: the SparkFun **Micro** BMI270 (SEN-22398) is effectively I2C-only (CS is not
    broken out). SPI would require swapping to the 1"×1" SEN-22397. Not needed.

---

## 2. Wiring details

### CAN bus (XIAO ↔ CAN Pal ↔ moteus-x1)

```
XIAO 3V3-OUT ── CAN Pal Vcc     (VIO is tied to Vcc → RX/TX are 3.3 V logic;
XIAO GND     ── CAN Pal GND      onboard AP3602A charge pump makes the 5 V internally)
XIAO D8 (GPIO8, TWAI TX) ── CAN Pal TX      (straight through, not crossed)
XIAO D3 (GPIO7, TWAI RX) ── CAN Pal RX
CAN Pal SLNT ── leave floating (internal pull-down = normal mode; high = listen-only)

CAN Pal H  ── twisted pair ── moteus-x1 CAN JST PH-3 pin 1 (CAN_H)
CAN Pal L  ── twisted pair ── moteus-x1 CAN JST PH-3 pin 2 (CAN_L)
CAN Pal terminal GND ─────── moteus-x1 CAN JST PH-3 pin 3 (GND)   ← common reference
```

- **Termination:** CAN Pal slide switch **ON** (it is a proper 2×60 Ω split termination
  with 4.7 nF center cap). moteus has **no onboard termination** → put the mjbots
  JST-PH3 CAN-FD terminator in the x1's second CAN jack (or solder 120 Ω). Both ends
  terminated; keep the bus short and stub-free (this is what makes 5 Mbps work).
- Verify the PH-3 pin order against the x1 silkscreen before crimping (mjbots pinout doc:
  1=CAN_H, 2=CAN_L, 3=GND).
- No power flows over the moteus CAN connector. Keep powering the XIAO from USB-C / the
  existing 5 V into VBUS. The x1's 5 V aux out is only 200 mA — too marginal for dual-band
  Wi-Fi TX bursts; don't use it for the XIAO.

### Bus timing (firmware-side, both phases)

- Arbitration 1 Mbps / data 5 Mbps, **sample point 0.666 in both phases** (moteus
  requires 0.666), SJW/DSJW as large as possible. moteus bit rates are fixed in its
  firmware — nothing to configure on the motor side.
- **Fallback if 5 M is marginal** (Espressif has formally tested the C5 at 4 M; the CTU
  core goes higher, and short buses generally run 5 M fine): clear the per-frame **BRS**
  flag on our side — moteus mirrors the query's BRS, so the whole bus drops to 1 Mbps
  while keeping FD frames. This is the officially documented fallback
  (`--can-disable-brs` in mjbots tooling). Still ample bandwidth: a 19-byte cmd+query
  exchange ≈ 0.5 ms round trip at 1 M.

### IMU (BMI270 Micro, Qwiic pigtail soldered to rear pads)

- SDA→GPIO2 (MTMS), SCL→GPIO3 (MTDI), 3V3, GND — see pin map. Pull-ups (2.2 kΩ) are on
  the breakout; chip supports up to 1 MHz I2C, target 400 kHz. Address 0x68.
- BMI270 init uploads a mandatory 8 KB Bosch config blob every power-on: `beginI2C()`
  takes ~200–300 ms at 400 kHz. Init inside the IMU task (as today), never blocking boot.

### Display link — ROLES FLIPPED (2026-07-13)

Original plan (C5 = slave @ 8, display = master) died on hardware: the
Arduino I2C slave driver never ACKs on ESP32-C5 silicon — the prebuilt IDF
libs only compile the legacy slave driver (CONFIG_I2C_ENABLE_SLAVE_DRIVER_
VERSION_2 is not set), and `Wire.begin(addr,...)` returns success while the
peripheral stays deaf. The C5's I2C *master* path works (BMI270 on LP-I2C
proved the silicon; HP I2C0 master is the standard driver).

Now: **C5 = bus master** on the same wires (D4/D5), **display = slave @ 8**
(the S3 slave role the old main board ran for months). C5 pushes the
unchanged 32-byte status frame at 10 Hz and polls a 32-byte command
mailbox (`I2C_CMD_MAILBOX`, byte-identical structs both sides, seq-deduped,
checksummed); screen commands are staged in the mailbox and collected
within ~100 ms. All command handlers, status struct, and ack/resend logic
survived the flip.

---

## 3. Toolchain

- Official `platformio/espressif32` is stuck on Arduino core 2.0.17 — **no C5, dead end**.
- Use the community **pioarduino** platform (Arduino 3.3.x / ESP-IDF 5.5.x), board id
  `seeed_xiao_esp32c5` (shipped since release 55.03.38):

```ini
[env:seeed_xiao_esp32c5]
platform = https://github.com/pioarduino/platform-espressif32/releases/download/55.03.39/platform-espressif32.zip
board = seeed_xiao_esp32c5
framework = arduino
monitor_speed = 115200
lib_deps =
    bblanchon/ArduinoJson @ ^6.18.5
    links2004/WebSockets @ ^2.7.1
```

- Arduino core 2.x→3.3.x is a breaking upgrade, but this codebase uses none of the broken
  APIs (no LEDC/analogWrite/old-timer/ADC-driver usage found). WiFi/WebSockets/ArduinoJson/
  Wire (incl. slave mode, `SOC_I2C_SUPPORT_SLAVE=1` on C5) all fine.
- **`driver/twai.h` does not exist on the C5 at all** (legacy driver is compiled out on
  FD-capable chips). CAN code must be rewritten against ESP-IDF 5.5's node API:
  `esp_twai.h` / `esp_twai_onchip.h` (`twai_new_node_onchip`, dual `bit_timing` +
  `data_timing`, per-frame `fdf`/`brs` flags, callback-driven RX). The precompiled
  Arduino libs include this component — usable directly from the sketch.

---

## 4. Software migration (by module)

| Module | Change |
|---|---|
| `CANCommunication` | **Full rewrite.** ODrive CANSimple (11-bit `node<<5\|cmd`) → moteus register protocol (16-bit source/dest ID, 0x8000 reply bit ⇒ extended IDs; little-endian multiplex subframes). Options: (a) mjbots `moteus-arduino` lib + ~100-line C5 backend (it's templated on a simple CanBus concept: `poll/available/receive/tryToSend` over its own `CANFDMessage`), or (b) mjbots `moteus_protocol.h` frame builders directly over the node API. RX callback → FreeRTOS queue consumed by MotorControlTask (keeps current architecture). |
| `MotorControl` | Control mapping is nearly 1:1 (below). Loop becomes query-driven instead of broadcast-driven: each cycle sends ONE position-mode command frame with the query bit; the reply carries position/velocity/torque. Replaces ODrive's 100 Hz pos/vel broadcast + 3–4 TX frames per cycle. |
| `Accelerometer` | Rewrite MPU6050 register code → BMI270 (SparkFun BMI270 Arduino Library if `Wire1` works; else Bosch bmi2 API over IDF LP-I2C). Keep the 50-sample averaging + sharedData path. |
| `I2CCommunication` | Pin numbers only (SDA 5→23, SCL 6→24). Protocol unchanged. |
| `WiFiCommunication`, `SerialCommunication`, `SharedData`, `Logging`, `ErrorHandling` | Port as-is; re-check task pinning (below). |
| Tasks | **C5 is single-core** (one 240 MHz RISC-V) vs S3's dual Xtensa. All `xTaskCreatePinnedToCore(..., 1)` must move to core 0 / no-affinity, and priorities re-tuned so the control task outranks Wi-Fi work. Watch the 500 Hz loop under Wi-Fi bursts; 8 MB PSRAM is available if RAM gets tight. |

### Control mapping (ODrive → moteus)

Force rendering today = velocity mode chasing an unreachable reel-in setpoint with a live
torque cap (the cap IS the rendered force). moteus equivalent, one frame per cycle:

| Concept | ODrive (today) | moteus (new) |
|---|---|---|
| Mode: render force | `AxisState=CLOSED_LOOP` + velocity control | Mode register (0x000) = **10** (position) |
| Mode: idle/sleep | `AxisState=IDLE` | Mode = **0** (stopped; also clears faults) |
| Unreachable chase | `Set_Input_Vel = -20 turns/s` | position (0x020) = **NaN**, velocity (0x021) = −20 rev/s |
| Force = live cap | `torque_soft_min` endpoint write (or Set_Limits current) | **maximum_torque (0x025) = \|sentTq\|** |
| Zone/recoil speed cap | `Set_Limits velocity_limit` | **velocity_limit (0x028)** |
| Feedback | 100 Hz pos/vel broadcast | query bit ⇒ reply: position 0x001, velocity 0x002, torque 0x003 |
| VBUS/temp telemetry | GET_VBUS 1 Hz | query 0x00d (voltage), 0x00e (temp) at low rate |
| Watchdog | none | `0x027` per-frame or `servo.default_timeout_s`; timeout ⇒ stopped = safe release |
| Units | motor turns, turns/s, Nm | output revolutions, rev/s, Nm — **1:1 carryover** |
| Node ID | 0 | **1** (moteus valid IDs 1–126; source/host = 0) |

Torque matrix / calibration anchors (0.5 Nm ≈ 1 lbf etc.) carry over as starting values if
the motor+spool stay the same; re-anchor with the existing `test_torque` cal probe.

### moteus bench prep (before any firmware work — needs fdcanusb/mjcanfd-usb-1x)

1. `moteus_tool --target 1 --calibrate` with the motor mounted free-spinning.
2. Set `id.id = 1`, verify `servo.default_timeout_s` + `servo.timeout_mode` (stopped),
   sane `servo.max_current_A` / velocity limits; `conf write`.
3. In tview, hand-verify the render recipe: `d pos nan -20 <maxT>` style commands produce
   the expected constant pull with a hard cap. Dump config into `moteus_x1/` (like
   `odrive_s1/my_config.json`).

---

## 5. Bring-up order (each step independently testable)

1. **Toolchain smoke test:** blink + Wi-Fi + WebSocket echo on the XIAO C5 (pioarduino env).
2. **IMU:** Qwiic on rear pads; try `Wire1` → IDF LP-I2C → bit-bang, in that order. WHO_AM_I
   (0x00 = 0x24), then streaming.
3. **CAN loopback:** TWAI-FD node in self-test/loopback at 1 M/5 M, verify FD frames.
4. **CAN ↔ moteus:** two-node bus, both terminations on. Send stop (Mode 0) + query,
   confirm reply. Then at 5 M under load; if errors, clear BRS and re-test at 1 M.
5. **Force rendering on the bench:** replicate today's feel (recoil, zone taper, weight
   gate, drop-catch) — the state machines are unchanged, only the transport swapped.
6. **Display link + full integration**, then re-anchor force calibration.

## 6. Risks / open items

- **5 Mbps data phase on the C5** — Espressif's formally tested figure is 4 M; short
  terminated bus expected to run 5 M; BRS-off @ 1 M is the sanctioned fallback. (Latency
  impact of fallback: negligible at our rates.)
- **LP-I2C under Arduino (`Wire1`) unproven** — mitigated by same-wiring fallbacks (IDF
  driver, bit-bang). Verify in step 2 before building anything on it.
- **I2C slave quirks on the new core** (v2 slave driver era) — existing checksum/seq
  protocol already defends; re-run the display-poll soak test.
- **Single-core scheduling** — 500 Hz control + Wi-Fi + I2C-slave ISR on one core; may
  need control-loop rate or priority adjustments.
- **Boot ROM prints on GPIO11 (D6)** at every reset — keep D6 for UART logging or leave
  free; don't hang reset-sensitive hardware on it.
- Included FPC antenna is the 2.4 GHz XIAO part — fine for current 2.4 GHz use; swap if
  5 GHz Wi-Fi 6 is ever wanted.
- Shopping: mjbots JST-PH3 CAN-FD terminator (+ crimped PH-3 leads), fdcanusb if not
  already owned (required — moteus cannot be calibrated from the MCU).

## 7. Row mode (added 2026-07-12, after the C5 port)

Row is its own control mode: a virtual Concept2-style flywheel in
MotorControl.cpp (one-way clutch with hysteresis, stiff coupling for the
catch, quadratic air-drag decay), rendered through the same torque-cap
pipeline — drop-catch and auto-sleep stay in force; only the near-home taper
shrinks to a pinch-only `row_zone`. Screen exposes gear/drag (1-10) via the
shared numpad; entering/leaving the row screen enables/disables the mode
(entry clears any latched weight — row and strength never stack).

Protocol changes (BOTH firmwares must be flashed together):
- `SharedStateData` grew 24 -> 32 bytes: + row_spm/row_drag/row_gear (u8,
  gear/drag echo 0 while row is off — the screen's ack signal) + row_watts
  (float). Checksum covers the new bytes automatically.
- New I2C command `SET_ROW` (3): {mask, gear, drag, row_enable} — mask bits
  0x1 gear / 0x2 drag / 0x4 enable-state.
- WS/HTTP "row" command now takes {"type":"on|off","gear":N,"drag":N}
  (legacy gear_ratio/damping accepted); metrics gained row_watts/row_spm.
- cal gained row tuning keys: row_kc, row_inertia, row_drag_base,
  row_return, row_max, row_zone (see setRowTuning) — tune on the bench over
  WS before trusting the screen defaults (gear 5 / drag 5).

## 8. Session log — bring-up 2026-07-12 → 2026-07-17 (state of the world)

**THE MACHINE WORKS.** Full chain live: screen ↔ C5 ↔ CAN-FD ↔ moteus-x1 ↔
2× RI115-PH KV40 (parallel, one shaft). Strength + row + force profiles +
web API all functional. What follows is everything a fresh session needs.

### Hardware truths (measured, not assumed)
- Motor pair calibrated as ONE motor: 40 poles, 0.038 Ω, 54 µH, Kv 40
  forced, `motor_position.output.sign = -1` (reel-in direction fix).
- Drivetrain: **~5 lbf per N·m** at the handle, **~5 revs per stroke**,
  capstan friction **~25% of load** (up/down asymmetry measured 2026-07-14:
  set 10 → 11/6 lb, set 20 → 20/12.5 before compensation).
- Bus: 48 V; CAN topology CAN Pal (term ON) → moteus (no term) → fdcanusb
  (term ON) daisy chain; C5 = CAN host id **4** (0 = tview/fdcanusb).
- Force ceiling **~48 lbf — deliberate** (`servo.max_current_A 40` = pair
  continuous). Headroom plan: 80 A + 1400 W → ~95 lb; ~104 A → ~120 lb but
  wire the RI115 thermistor to x1 AUX2 first; PSU must source ~20 A @ 48 V.

### Architecture decisions that were forced by reality
- **Display link roles FLIPPED** (§ Display link): C5 Arduino I2C slave
  never ACKs on this silicon (v2 slave driver not compiled into prebuilt
  libs) → C5 is bus MASTER (10 Hz status push + mailbox poll), display is
  slave @8. Structs byte-identical both firmwares → **always flash C5 +
  display as a pair** after protocol changes.
- **Canonical weight unit is POUNDS** everywhere (CommandMsg.weight_lb;
  /metrics active/pending_weight in lb). The old `weight_kg` name caused a
  real bug: web-set weights rendered at 45% force. Fixed 2026-07-14.
- BMI270 lives on LP-I2C (rear GPIO2/3 pads) and works.
- PlatformIO: C5 project has isolated `packages_dir` (packages-pioarduino)
  — official + pioarduino platforms clobber each other's riscv toolchain
  in the shared dir otherwise.
- USB CDC is non-blocking (`setTxTimeoutMs(0)`) — a half-attached monitor
  used to stall the 500 Hz control loop.

### Control design (strength)
500 Hz moteus position-mode stream: position=NaN, velocity = zone-clamped
reel-in chase, maximum_torque = rendered force. Pipeline order: weight gate
(pull-to-confirm) → matrix (force_scale 0.40, midpoint-anchored) → zone
taper → concentric-only unloading (con_pct 0-100, screen % label) →
directional friction comp (fric_k 0.17, boosts lowering/trims pulling) →
drop-catch shed → symmetric cap to moteus. Idle = 50 Hz query-only stream
(wake detection); 1 Hz telemetry (vbus/iq/temp/mode/fault + stop-recovery).

### Row mode
Virtual flywheel (one-way clutch + quadratic decay), gear/drag 1-10 from
the screen (defaults 1/1), watts + SPM computed and shipped. Anti-chatter:
high inertia (5) + wide hysteresis + fast-attack/slow-release shaping.
Enter/leave = row screen enter/leave; row and strength never stack.

### Force profiles (all dHome-anchored = revs from dock, repeatable)
constant / linear (chains + resistance-band recipes in WEB_API.md) /
detents (raised-cosine notches, re-enabled) / pulse. Compose in that order.

### Baked cal defaults (current compiled truth — see CAL_REFERENCE.md)
force_scale 0.40 · fric_k 0.17 band 0.6 · con 0 (0.3/1.5) · recoil_tq 0.3
recoil_vel 8 (dock 2) · zone 1.0 · gate 1.1/0.3/0.15/0.4 · wake 0.25 ·
drop 6/15/1.5 · row_kc 2.5 inertia 5 drag_base 0.15 return 0.6 max 10
zone 0.5. Cal is RAM-only — bake keepers here + reflash (NVS persistence
was offered, declined for now).

### Operational gotchas (hard-won)
- **Mute the C5 before tview/moteus_tool** (`cal {"can_quiet":true}`, boots
  live) and close tview before the calibration script (COM port exclusive).
  Power-cycle the moteus after any killed diagnostic session.
- moteus calibration: config-before-calibrate (servopos nan clears fault
  39); calibrate_moteus.py owns the port handoff; report JSON is ground
  truth if post-cal readback wedges.
- WiFi: KNOWN_NETWORKS list; hotspot currently impersonates home SSID
  (WPA2, 2.4 GHz compat mode). Boot is offline-tolerant; mDNS can go stale
  after network switch — the [hb] heartbeat IP is ground truth.
- Serial: [boot] banner + 5 s [hb] (wifi/can/tx/drop/rx/i2c push+cmd/vbus)
  + [wg]/[row] 4 Hz (cal debug toggles). Display -fast env has NO USB
  serial — flash plain T-Display-AMOLED env to hear it.
- Display upload_port pinned COM3 in its platformio.ini.
- Web app: HTTPS pages can't call the http device (mixed content) — utility
  must run from an http origin; device-served control page offered/pending.

### Open items (ordered, none blocking)
1. Bake session-tuned cal values as they settle (user reports numbers).
2. Force ceiling raise (deferred; plan above).
3. Device-served phone control page (solves mobile HTTPS wall + no-internet).
4. Friction comp acceptance at rep speed; fric_k → 0.20 candidate.
5. Bench-validate detents/chains/band profiles; SPM label on row screen
   (data already transmitted); concentric label ↔ app two-writer sync.
6. Strip bring-up scaffolding (wiring probe, extra prints) when stable.
7. NVS cal persistence if reflash-to-bake gets old.

## 9. Key sources

- ESP32-C5 datasheet v1.3 (I2C count §4.2.1.3; TWAI-FD §4.2.1.6; strapping ch. 3)
- ESP-IDF v5.5 TWAI (esp32c5) + I2C docs; esp-idf issues #17453 (4 M tested), #17461
- Seeed XIAO ESP32-C5 wiki (pinout, Arduino ≥3.3.5, PlatformIO)
- pioarduino platform-espressif32 (board `seeed_xiao_esp32c5`, ≥55.03.38)
- mjbots: moteus reference/protocol docs, fw/moteus.cc (fixed 1M/5M, BRS mirroring),
  moteus-x1 product page (2× JST PH-3, no termination, 5V/200mA aux), moteus-arduino
- NXP TJA1051 datasheet Rev. 9 ("timing guaranteed … up to 5 Mbit/s in the CAN FD fast
  phase"); Adafruit CAN Pal schematic (VIO=Vcc, AP3602A charge pump, switched split term.)
- SparkFun BMI270 hookup guide + Eagle files (Micro = I2C-only, 2.2 kΩ pull-ups, 0x68)

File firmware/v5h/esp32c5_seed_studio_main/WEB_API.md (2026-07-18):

# Digital Weight — device web API (for the app's device-utility page)

The C5 main board runs two servers on the local network:

| | |
|---|---|
| HTTP | `http://<device-ip>/` (port 80) — commands + one-shot reads |
| WebSocket | `ws://<device-ip>:81` — same commands + pushed telemetry every ~400 ms |
| mDNS name | `digital-weight.local` (unreliable from browsers — prefer the IP, shown in the `[hb]` serial line and your router's DHCP table) |

CORS is wide open on the device (`Access-Control-Allow-Origin: *`, OPTIONS
preflight handled), so any page — including localhost dev servers — can call
it directly from browser JS.

## ⚠️ The HTTPS gotcha (read first)

The device speaks plain `http://` and `ws://` — it has no TLS. Browsers
**block** those from pages served over `https://` (mixed content). The
production app on GitHub Pages is HTTPS, so the device utility will NOT work
there as-is. Options, best first:

1. **Run the utility from a localhost dev server** (`http://localhost:5173`
   etc.) — http page → http device = allowed, and this matches when you'd
   actually use it (same LAN as the machine).
2. Serve/open the utility page itself over plain http or `file://`.
3. (Later, if it must live in the prod app: a tiny local bridge or allowing
   the browser's per-site insecure-content exception — both clunky; prefer 1.)

## Commands (HTTP POST `/command`, body = JSON; or send the same JSON as a WS text frame)

| command | body example | effect |
|---|---|---|
| `strength` | `{"command":"strength","weight_lbs":10}` (or `weight_kg`, converted) | set weight — the physical pull-to-confirm gate still applies. **The device's canonical weight unit is POUNDS**: `active_weight`/`pending_weight` in /metrics and the WS broadcast are lb, and the HTTP ack echoes `weight_lbs`. Do NOT convert reads from kg. |
| `idle` | `{"command":"idle"}` | weight 0 / off (also exits row mode) — make this the big red button |
| `row` | `{"command":"row","type":"on","gear":5,"drag":5}` / `"off"` | enter/leave row mode |
| `cal` | `{"command":"cal","recoil_tq":0.8,"can_quiet":true}` | live tuning — full key list in CAL_REFERENCE.md. RAM-only; reboot reverts |
| `cal` (concentric) | `{"command":"cal","con_pct":100}` | concentric-only unloading, 0-100: % of force removed when not actively pulling out (0 = normal both directions; keep-taut/recoil floor always remains). `con_lo`/`con_hi` (rev/s) tune where "pulling" begins/ends. Same control the strength screen's % label sets. |
| `pulse` | see **Force profiles** below | haptic sine ripple on the set weight |
| `force` | see **Force profiles** below | force-vs-position profile (`off`/`constant`/`linear`) |
| `detent` | see **Force profiles** below | tactile notches along the stroke |
| `mode` | `{"command":"mode","type":"strength"}` | status label bookkeeping only |

## Force profiles

All position-based profiles use **revs of pull from the dock** (a full
stroke on this machine is ~5 revs) and multiply the SET weight — the safety
stack (gate, drop-catch, concentric, dock taper) applies after, unchanged.
Profiles persist until changed (RAM; reboot reverts to `constant`/100%).

```json
// constant (the default) — 100% of the set weight everywhere
{"command":"force","type":"constant","strength":100}

// CHAINS — starts at 40% off the floor, full weight by 4 revs of pull
{"command":"force","type":"linear","start_strength":40,"strength":100,
 "start_position":0.3,"saturation_position":4.0}

// RESISTANCE BAND — light at the bottom, overloads past 100% at the top
{"command":"force","type":"linear","start_strength":15,"strength":140,
 "start_position":0.2,"saturation_position":4.5}

// DETENTS — tactile clicks: force dips strength% at every step_position
// revs, starting start_position revs from the dock, for total_steps notches
{"command":"detent","type":"on","strength":40,"start_position":0.5,
 "step_position":0.8,"total_steps":5}
{"command":"detent","type":"off"}

// PULSE — sine ripple, strength% of a 0.4x-weight envelope at frequency Hz
{"command":"pulse","type":"on","strength":50,"frequency":8,"duration":0}
{"command":"pulse","type":"off"}
```

Notes: `strength` above 100 is allowed on `linear` (that's the band
overload). Below `start_position` the linear profile holds
`start_strength`%, not zero. Profiles compose in order: force profile →
detents → pulse.

HTTP responses are small JSON (`{"result":"strength","weight_kg":4.5,...}`).
The `cal` response echoes `force_scale`, `zero_m1`, `brs`, `can_quiet`.
NOTE: there is no read-back for most cal values — a tuning UI should treat
"what I last sent" as its state, seeded from the defaults table in
CAL_REFERENCE.md.

## Reads

- `GET /metrics` — `{position, velocity, force, voltage, current,
  accelerometer_*, gyro_*, virtual_velocity, row_watts, row_spm,
  active_weight, pending_weight, weight_pending, status, t_*_ms latency
  stamps}` — `weight_pending=1` means a commanded weight awaits the user's
  confirming pull; show "N lb pending" until it clears.
- `GET /health` — `{"status":"OK","uptime":<ms>}`

## WebSocket telemetry & RTT

Connect to `ws://<ip>:81`. You receive a metrics frame (`{"type":"metrics",
...}` — same fields as `/metrics`) every ~400 ms without asking. Any command
you send gets an ack frame; include `"client_ts": Date.now()` in a command
and the ack echoes it — subtract for live round-trip latency, handy for a
connection-quality indicator. (Broadcasts pause ~250 ms after a command to
keep the command path snappy.)

## Ready-to-paste JS

```js
// ---- config ----
const DEVICE = localStorage.getItem('dw_ip') || '192.168.1.140';

// ---- one-shot command over HTTP ----
async function dwCommand(body) {
  const r = await fetch(`http://${DEVICE}/command`, {
    method: 'POST',
    body: JSON.stringify(body),
  });
  return r.json();
}
// examples:
// dwCommand({command:'strength', weight_lbs: 10})
// dwCommand({command:'idle'})
// dwCommand({command:'cal', can_quiet: true})     // mute CAN (bench mode)
// dwCommand({command:'cal', recoil_tq: 0.8, recoil_vel: 10})

// ---- live telemetry over WebSocket, with auto-reconnect ----
function dwConnect(onMetrics, onStatus = () => {}) {
  let ws, alive = false;
  const open = () => {
    ws = new WebSocket(`ws://${DEVICE}:81`);
    ws.onopen = () => { alive = true; onStatus('connected'); };
    ws.onclose = () => { alive = false; onStatus('disconnected'); setTimeout(open, 2000); };
    ws.onmessage = (e) => {
      const m = JSON.parse(e.data);
      if (m.type === 'metrics') onMetrics(m);
      else if (m.client_ts) onStatus(`rtt ${Date.now() - m.client_ts} ms`);
    };
  };
  open();
  return {
    send: (body) => alive && ws.send(JSON.stringify({ ...body, client_ts: Date.now() })),
    isAlive: () => alive,
  };
}

// usage:
// const dw = dwConnect(m => {
//   ui.voltage.textContent = m.voltage.toFixed(1) + 'V';
//   ui.force.textContent   = m.force.toFixed(0) + 'N';
//   ui.watts.textContent   = m.row_watts.toFixed(0);
//   chart.push(m.position, m.velocity);
// });
// dw.send({command:'strength', weight_lbs: 15});
```

## Utility-page design notes

- **Zero-weight button**: prominent, one tap, sends `{command:'idle'}`. It is
  the software e-stop (force physically releases; strap self-stows).
- **CAN mute toggle** (`cal can_quiet`): label it clearly — while muted the
  machine is fully inert (screen commands queue but nothing moves) and the
  screen's voltage goes stale. It exists for moteus-calibration bench
  sessions. State is echoed in every `cal` response.
- **Cal sliders**: send on release (not on drag) — commands coalesce on the
  device but there's no need to spam. Group per CAL_REFERENCE.md sections.
  Add a "copy JSON" button that exports the session's accumulated cal deltas
  — that's exactly what gets baked into firmware defaults afterwards.
- **Persistence**: cal is RAM-only. A reboot silently reverts — consider
  showing uptime from `/health` and warning when it resets (uptime went
  backwards = device rebooted = your tuning session is gone from the device).
- Weight changes still require the user to pull into them (safety gate) —
  reflect it: while `weight_pending=1`, show `pending_weight` as "awaiting
  pull-to-confirm" next to `active_weight` (both in /metrics and the WS
  broadcast).
- **Concentric % has two writers and no read-back**: the strength screen's
  % label and the app's `con_pct` both set the same device value; last
  writer wins, and the screen label does NOT update when the app changes it
  (it shows the screen's own last-set value). Treat the app's slider the
  same way — it reflects what the app last sent. Applies instantly, no
  confirmation pull needed (it only ever unloads).

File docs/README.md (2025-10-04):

# Documentation Build Script

This directory contains the Sphinx documentation for the Open Workout System API.

## Quick Start

To build the documentation, simply run:

```batch
# Windows Batch (recommended)
build_docs.bat

# Or PowerShell
.\build_docs.ps1
```

This script will:
1. Install/update all required Python packages
2. Build the HTML documentation
3. Open the documentation in your default web browser

## Manual Build

If you prefer to build manually:

```batch
# Install requirements
pip install -r requirements.txt

# Build documentation
python -m sphinx.cmd.build -b html -W . build

# View results
start build/index.html
```

## Files

- `conf.py` - Sphinx configuration
- `index.rst` - Main documentation page
- `api.rst` - API reference
- `requirements.txt` - Python dependencies
- `build_docs.bat` - Automated build script (Windows Batch)
- `build_docs.ps1` - Automated build script (PowerShell)
- `Makefile` / `make.bat` - Alternative build system

The built documentation will be in the `build/` directory.

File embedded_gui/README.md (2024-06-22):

# Embedded GUI for V4 - AMOLED 1p9 Project

## Release Date

June 2024, as demonstrated at open sauce SF

## Overview

- Used squareline 1.3.3 studio for this design (free license version)
- Load the AMOLED 1p9 project
- Strength is functional
- All other screens are a work in progress and will update here when function is complete

## Pending functions

- Functional value input
- Setting mappings to the device
- Row mode
- Enhancements to come for mode and setting changes

## GUI Screens

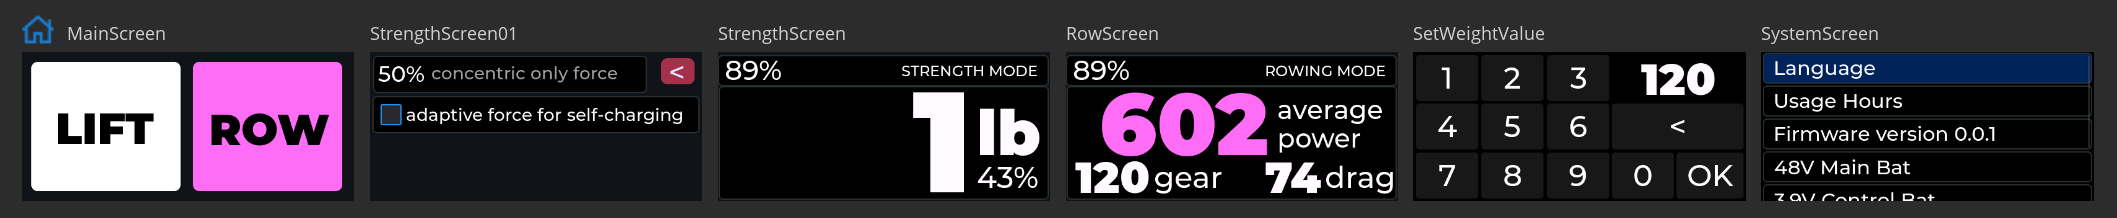
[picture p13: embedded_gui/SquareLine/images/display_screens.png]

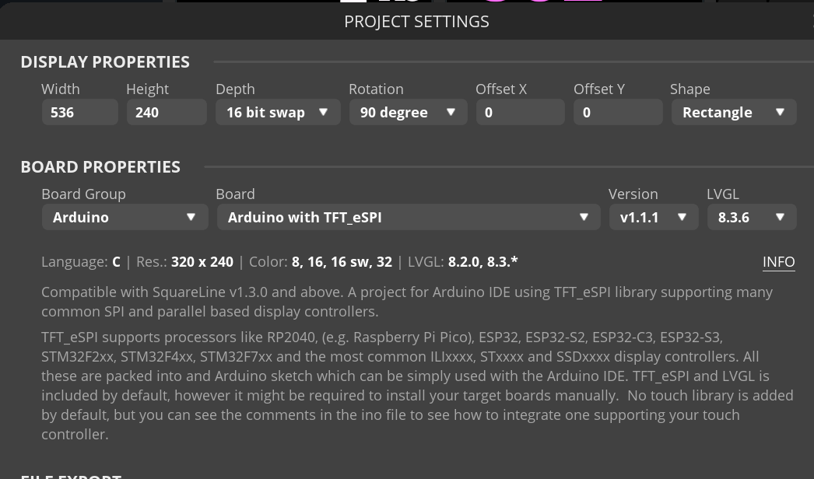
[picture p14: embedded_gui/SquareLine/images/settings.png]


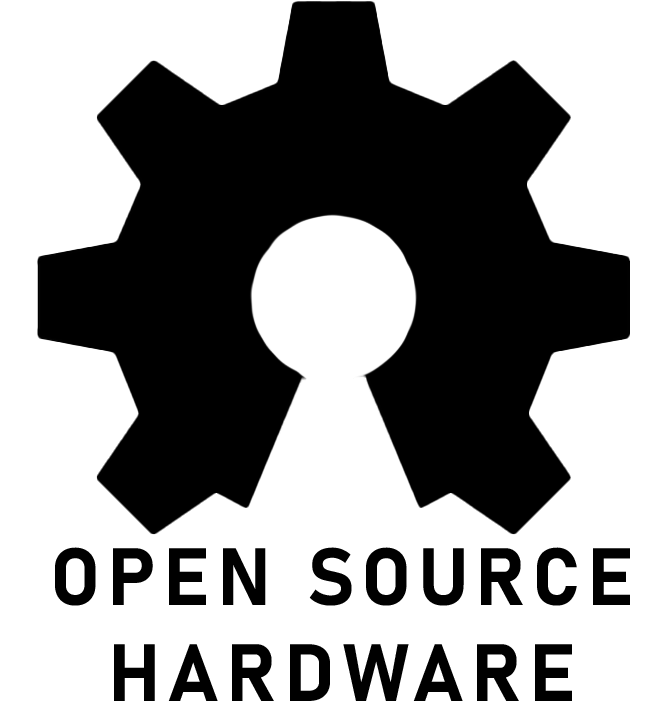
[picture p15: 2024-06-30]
images/open_hardware_dark.png

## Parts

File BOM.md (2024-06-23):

# Bill of Materials (BOM) for Digital Weight Project

| Item Number | Part Name | Part Number | Quantity | Description | Supplier | Unit Price | Total Price | Purchase Link |
|---|---|---|---|---|---|---|---|---|
| 1 | PETG 3D Printed Body | N/A | 1 | Custom 3D printed enclosure | In-house | N/A | N/A | No purchase link added() |
| 2 | Seed Studio ESP32-S3 | ESP32-S3 | 1 | Dual core mcu with Wi-Fi and BLE | DigiKey | $7.49 | $7.49 | [Buy Here](https://www.digikey.com/en/products/detail/seeed-technology-co-ltd/113991114/19285530) |
| 3 | BLDC Motor (Master) | M8312S 100KV | 1 | Brushless DC Motor 90KV | Supplier XYZ | $53.00 | $53.00 | [Buy Here](https://www.aliexpress.us/item/3256802425926647.html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) |
| 4 | Odrive Pro heat spreader | N/A | 1 | Odrive Pro heat spreader | ODrive Robotics | $12.00 | $12.00 | [Buy Here](https://shop.odriverobotics.com/products/heat-spreader-plate-for-odrive-pro) |
| 5 | Motor mount plate | N/A | 1 | Motor mount plate | ODrive Robotics | $12.00 | $12.00 | [Buy Here](https://shop.odriverobotics.com/products/pancake-motor-plate) |
| 6 | BLDC Motor (Slave) | M8325S 100KV | 1 | Included in combo below | ODrive Robotics | $0.00 | $0.00 | No purchase link added() |
| 7 | ODrive S1 Motor Controller (Master) | ODrive-S1 | 1 | Included in combo below | ODrive Robotics | $0.00 | $0.00 | No purchase link added() |
| 8 | ODrive Combo S1 Kit | ODrive-Kit | 1 | S1 controller with motor and mounts | ODrive Robotics | $329.00 | $329.00 | [Buy Here](https://shop.odriverobotics.com/products/s1-and-m8325s-start-kit) |
| 9 | ODrive Pro Motor Controller (Slave) | ODrive-Pro | 1 | Motor controller for slave motor | ODrive Robotics | $230.00 | $230.00 | [Buy Here](https://shop.odriverobotics.com/products/odrive-pro) |
| 10 | 12S 2170 Lithium-Ion Custom Pack | 12S-2170 | 12 | MOLICEL/NPE INR-21700-P42A 45A 4200MAH FLAT TOP 21700 BATTERY | LIION | $4.85 | $58.20 | [Buy Here](https://liionwholesale.com/collections/batteries/products/molicel-npe-inr-21700-p42a-45a-4200mah-flat-top-21700-battery-authorized-distributor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) |
| 11 | Nickel Strip | N/A | 1 | Nickel strip for battery pack | LIION | N/A | N/A | [Buy Here](https://liionwholesale.com/collections/nickel-strip-and-nickel-tabs/products/pure-nickel-strip-roll-0-15mm-0-2mm-thickness-6mm-10mm-widths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) |
| 12 | 36T Planetary Gear | N/A | 1 | ~5:1 reduction gear for slave motor | Aliexpress | $23.75 | $23.75 | [Buy Here](https://www.aliexpress.us/item/3256803958138585.html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) |
| 13 | LILYGO T-Display S3 AMOLED | H681 | 1 | Touch non-soldered H681 version | LILYGO | $30.00 | $30.00 | [Buy Here](https://www.lilygo.cc/products/t-display-s3-amoled?variant=43228221636789) |
| 14 | ANO Directional Nav/Scroll Wheel | ANO-Scroll | 1 | Rotary encoder for navigation and scrolling | ANO Electronics | $15.00 | $15.00 | [Buy Here](https://example.com/ano-scroll-wheel) |
| 15 | LSM6DS33 Accelerometer and Gyro | LSM6DS33 | 1 | 6-axis accelerometer and gyroscope | Pololu | $15.00 | $15.00 | [Buy Here](https://www.pololu.com/product/2736) |
| 16 | 1-inch Seatbelt Webbing Nylon Strap | N/A | 20 | 20 feet of strong nylon strap with seatbelt webbing | Strapworks | $0.50 | $10.00 | [Buy Here](https://www.strapworks.com/1-inch-seatbelt-nylon-black) |
| 17 | 70x10mm Ring Bearing | N/A | 1 | Bearing for main drive | Uxcell Amazon | $14.00 | $14.00 | [Buy Here](https://www.amazon.com/gp/product/B0B5XQBXMH/ref=ppx_yo_dt_b_search_asin_title?ie=UTF8&th=1) |
| 18 | 45x7mm Ring Bearing | N/A | 2 | Bearing for slave motor | Uxcell Amazon | $3.00 | $6.00 | [Buy Here](https://www.amazon.com/gp/product/B09D2J9P82/ref=ppx_yo_dt_b_search_asin_title?ie=UTF8&th=1) |
| 19 | C-Channel Steel (Output Arm) | N/A | 1 | Steel arm for output | Steel Supplier | $5.00 | $5.00 | No purchase link added() |
| 20 | Misc Metric Screws and Inserts | N/A | Assorted | Various screws and threaded inserts | Hardware Supplier | N/A | N/A | No purchase link added() |
| 21 | CAN transceiver | N/A | 1 | CAN transceiver board | PCB Supplier | $6.00 | $6.00 | [Buy Here](https://www.amazon.com/gp/product/B0BCJ31N2V/ref=ppx_yo_dt_b_search_asin_title?ie=UTF8&psc=1) |
| 22 | Grip tape (cattongue) | N/A | 1 | Grip tape for bottom of unit to avoid slip | Amazon | N/A | N/A | [Buy Here](https://www.amazon.com/gp/product/B08CS3Q3Y4/ref=ppx_yo_dt_b_search_asin_title?ie=UTF8&psc=1) |

**Total Cost:** $826.44 (Approx)

Note: Prices are estimates and suppliers are placeholders. Actual costs and suppliers may vary.

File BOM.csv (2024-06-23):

Part Name | Part Number | Quantity | Description | Supplier | Unit Price | Purchase Link
PETG 3D Printed Body | N/A | 1 | Custom 3D printed enclosure | In-house | N/A | N/A
Seed Studio ESP32-S3 | ESP32-S3 | 1 | Dual core mcu with Wi-Fi and BLE | DigiKey | 7.49 | https://www.digikey.com/en/products/detail/seeed-technology-co-ltd/113991114/19285530
BLDC Motor (Master) | M8312S 100KV | 1 | Brushless DC Motor 90KV | Supplier XYZ | 53.00 | https://www.aliexpress.us/item/3256802425926647.html
Odrive Pro heat spreader | N/A | 1 | Odrive Pro heat spreader | ODrive Robotics | 12.00 | https://shop.odriverobotics.com/products/heat-spreader-plate-for-odrive-pro
Motor mount plate | N/A | 1 | Motor mount plate | ODrive Robotics | 12.00 | https://shop.odriverobotics.com/products/pancake-motor-plate
BLDC Motor (Slave) | M8325S 100KV | 1 | Included in combo below | ODrive Robotics | 0.00 | N/A
ODrive S1 Motor Controller (Master) | ODrive-S1 | 1 | Included in combo below | ODrive Robotics | 0.00 | N/A
ODrive Combo S1 Kit | ODrive-Kit | 1 | S1 controller with motor and mounts | ODrive Robotics | 329.00 | https://shop.odriverobotics.com/products/s1-and-m8325s-start-kit
ODrive Pro Motor Controller (Slave) | ODrive-Pro | 1 | Motor controller for slave motor | ODrive Robotics | 230.00 | https://shop.odriverobotics.com/products/odrive-pro
12S 2170 Lithium-Ion Custom Pack | 12S-2170 | 12 | MOLICEL/NPE INR-21700-P42A 45A 4200MAH FLAT TOP 21700 BATTERY | LIION | 4.85 | https://liionwholesale.com/collections/batteries/products/molicel-npe-inr-21700-p42a-45a-4200mah-flat-top-21700-battery-authorized-distributor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
Nickel Strip | N/A | 1 | Nickel strip for battery pack | LIION | N/A | https://liionwholesale.com/collections/nickel-strip-and-nickel-tabs/products/pure-nickel-strip-roll-0-15mm-0-2mm-thickness-6mm-10mm-widths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
36T Planetary Gear | N/A | 1 | ~5:1 reduction gear for slave motor | Aliexpress | 23.75 | https://www.aliexpress.us/item/3256803958138585.html
LILYGO T-Display S3 AMOLED | H681 | 1 | Touch non-soldered H681 version | LILYGO | 30.00 | https://www.lilygo.cc/products/t-display-s3-amoled?variant=43228221636789
ANO Directional Nav/Scroll Wheel | ANO-Scroll | 1 | Rotary encoder for navigation and scrolling | ANO Electronics | 15.00 | https://example.com/ano-scroll-wheel
LSM6DS33 Accelerometer and Gyro | LSM6DS33 | 1 | 6-axis accelerometer and gyroscope | Pololu | 15.00 | https://www.pololu.com/product/2736
1-inch Seatbelt Webbing Nylon Strap | N/A | 20 | 20 feet of strong nylon strap with seatbelt webbing | Strapworks | 0.5 | https://www.strapworks.com/1-inch-seatbelt-nylon-black
70x10mm Ring Bearing | N/A | 1 | Bearing for main drive | Uxcell Amazon | 14.00 | https://www.amazon.com/gp/product/B0B5XQBXMH/ref=ppx_yo_dt_b_search_asin_title?ie=UTF8&th=1
45x7mm Ring Bearing | N/A | 2 | Bearing for slave motor | Uxcell Amazon | 3.00 | https://www.amazon.com/gp/product/B09D2J9P82/ref=ppx_yo_dt_b_search_asin_title?ie=UTF8&th=1
C-Channel Steel (Output Arm) | N/A | 1 | Steel arm for output | Steel Supplier | 5.00 | N/A
Misc Metric Screws and Inserts | N/A | Assorted | Various screws and threaded inserts | Hardware Supplier | 10.00 | N/A
CAN transceiver | N/A | 1 | CAN transceiver board | PCB Supplier | 6.00 | https://www.amazon.com/gp/product/B0BCJ31N2V/ref=ppx_yo_dt_b_search_asin_title?ie=UTF8&psc=1
Grip tape (cattongue) | N/A | 1 | Grip tape for bottom of unit to avoid slip | Amazon | N/A | https://www.amazon.com/gp/product/B08CS3Q3Y4/ref=ppx_yo_dt_b_search_asin_title?ie=UTF8&psc=1

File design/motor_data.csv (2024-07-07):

weight | gear ratio | kv | max current | max voltage | phase resistance | max continuous current | price | supplier | link
841 | 5.5 | 100 | 60 | 60 | 44 | 10 | 120 | ODrive Robotics M8325s - 100kv | https://shop.odriverobotics.com/products/m8325s
750 | 5.5 | 55 | 60 | 48 | 65 | 20 | 170 | Cube Mars RO100 Frameless kv55 | https://www.cubemars.com/goods-1159-RO100.html
600 | 5.5 | 105 | 47.6 | 48 | 65 | 16.9 | 140 | Cube Mars RI100 Frameless kv105 | https://www.cubemars.com/goods-859-RI100.html
1200 | 1 | 20 | 100 | 48 | 65 | 40 | 140 | Custom | N/A

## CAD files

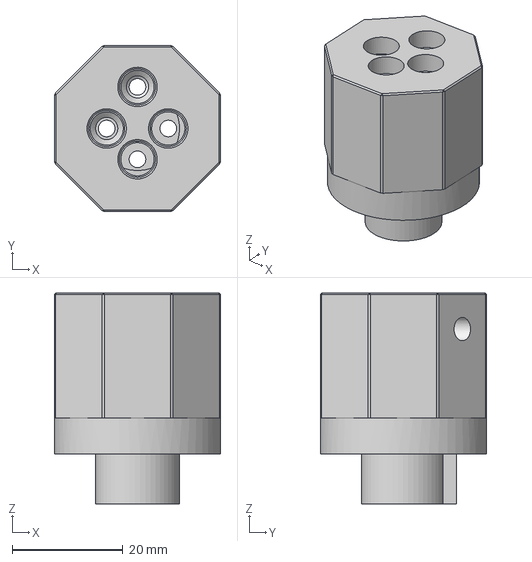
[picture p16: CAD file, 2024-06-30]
cad/v4/STEP_FILES/spool_main_drive.stp
30.0 x 30.0 x 38.0 mm

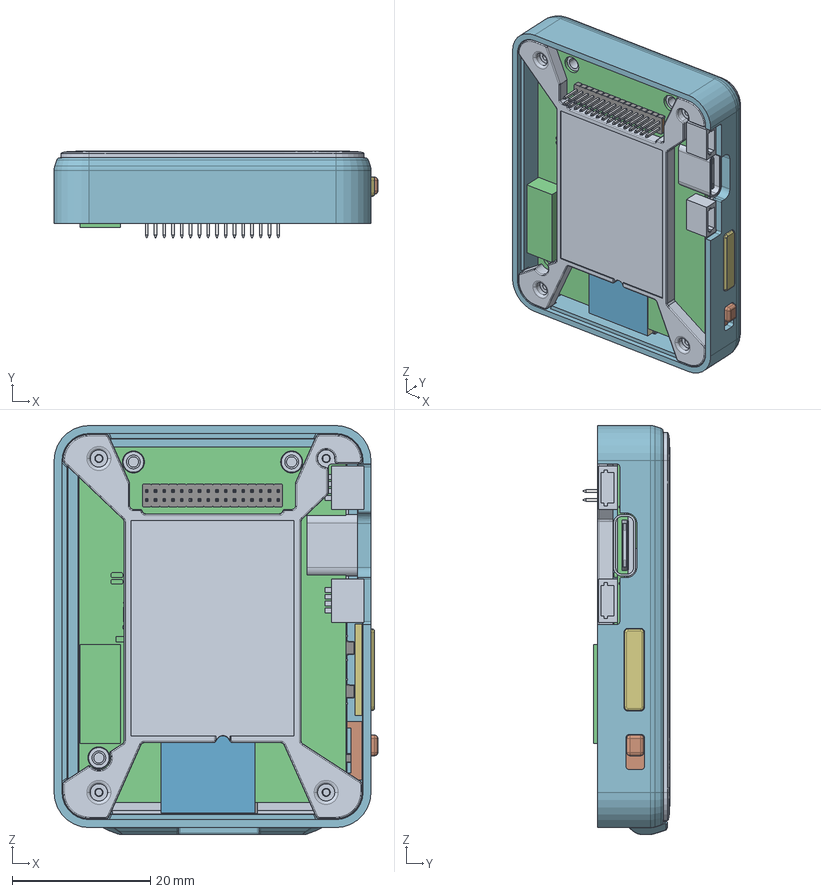
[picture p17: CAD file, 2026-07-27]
cad/v5h/inventor/T4-S3-AMOLED-Full.stp
46.9 x 12.6 x 59.2 mm
0-ALL_19_12
0-HOLDER_56_13
0-PCB_31_2
T_DISPLAY_S3_1_1
PRT0001_1_1
COMPOUND-20993_1_MIR_1_1-106840
COMPOUND-20993_2_MIR_1_1-121710
COMPOUND-20993_1_MIR_1_1-124087
COMPOUND-20993_2_MIR_1_1-138957
TEPC
BOARD

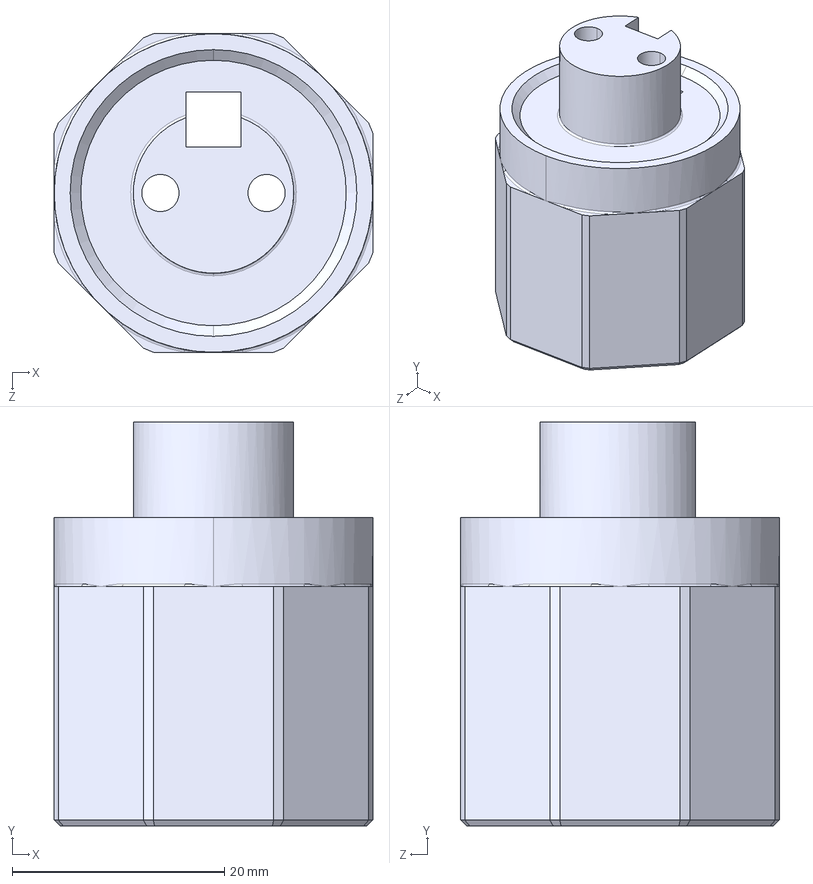
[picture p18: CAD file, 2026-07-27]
cad/v5h/inventor/SpoolMainDriveKeyMKII.STEP
30.0 x 38.0 x 30.0 mm

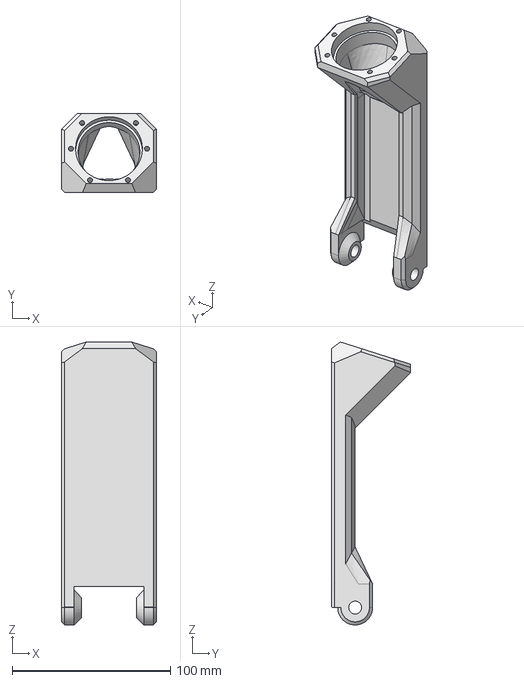
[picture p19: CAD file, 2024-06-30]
cad/v4/STEP_FILES/arm_main.stp
60.0 x 50.0 x 178.6 mm

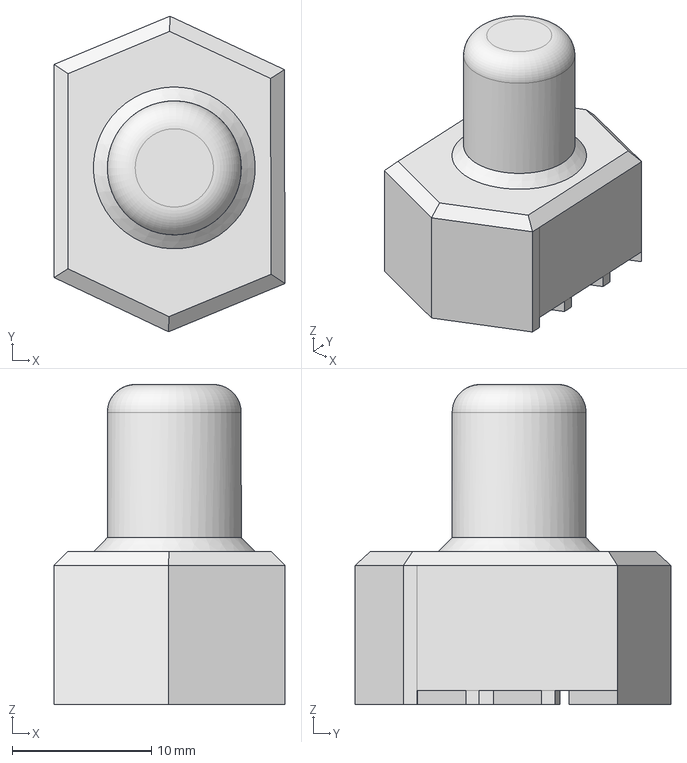
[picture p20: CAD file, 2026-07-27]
cad/v5h/inventor/3Dprints/stamp.stp
16.6 x 22.7 x 23.0 mm

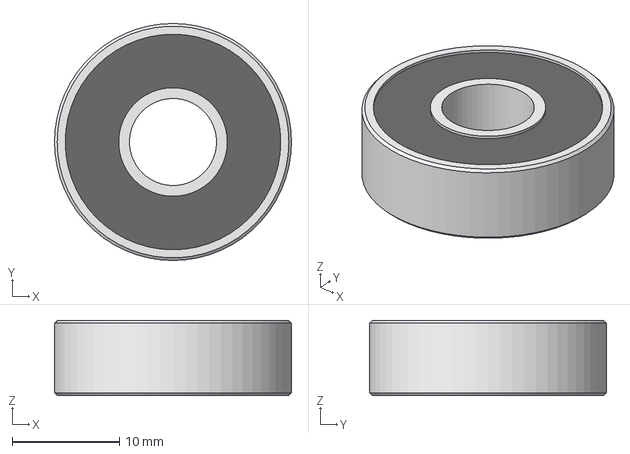
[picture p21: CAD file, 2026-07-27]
cad/v5h/inventor/bearings/bearing_12x8x8.stp
22.1 x 22.1 x 7.00 mm

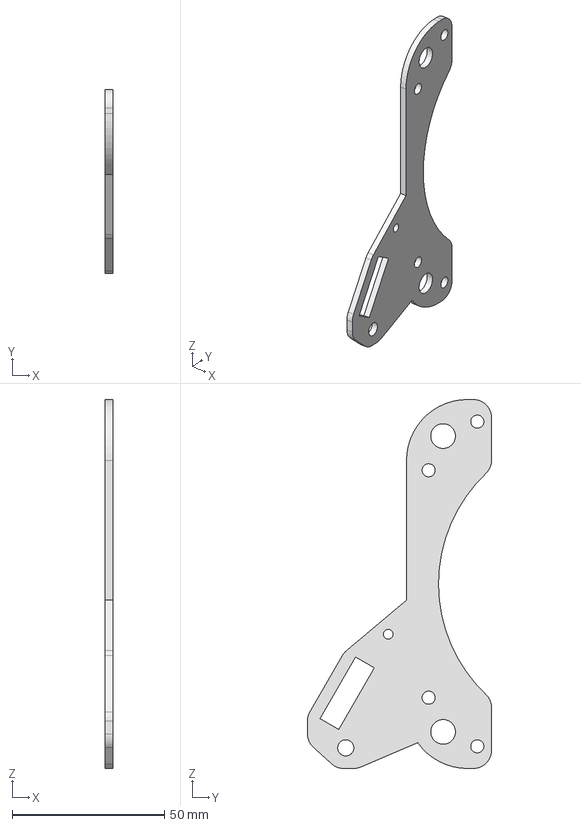
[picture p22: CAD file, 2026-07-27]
cad/v5h/inventor/CNC/output_support.stp
2.54 x 60.4 x 121.0 mm

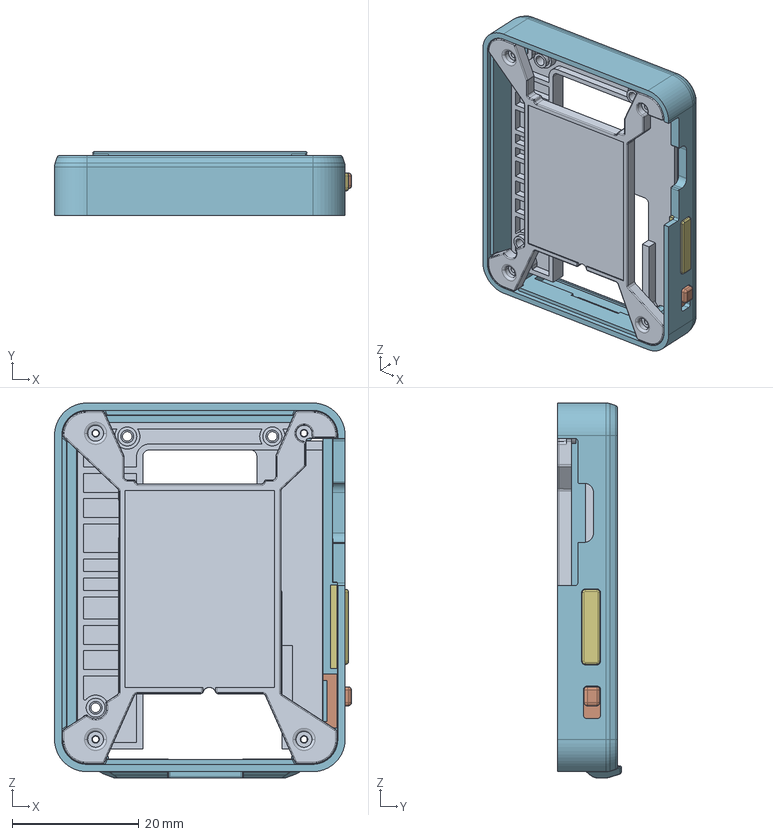
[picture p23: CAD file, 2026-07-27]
cad/v5h/inventor/lilygo_t4_case.stp
46.9 x 10.1 x 59.2 mm
0-HOLDER_56_13

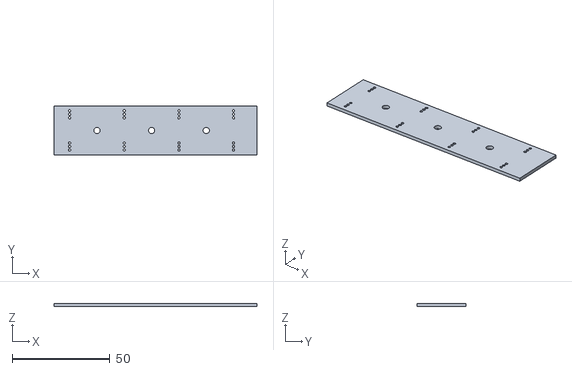
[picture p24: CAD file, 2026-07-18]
electrical/battery_pcb/LiFePO4_PCB_25x100/rear_bat_pcb.stl
104.0 x 25.0 x 1.51

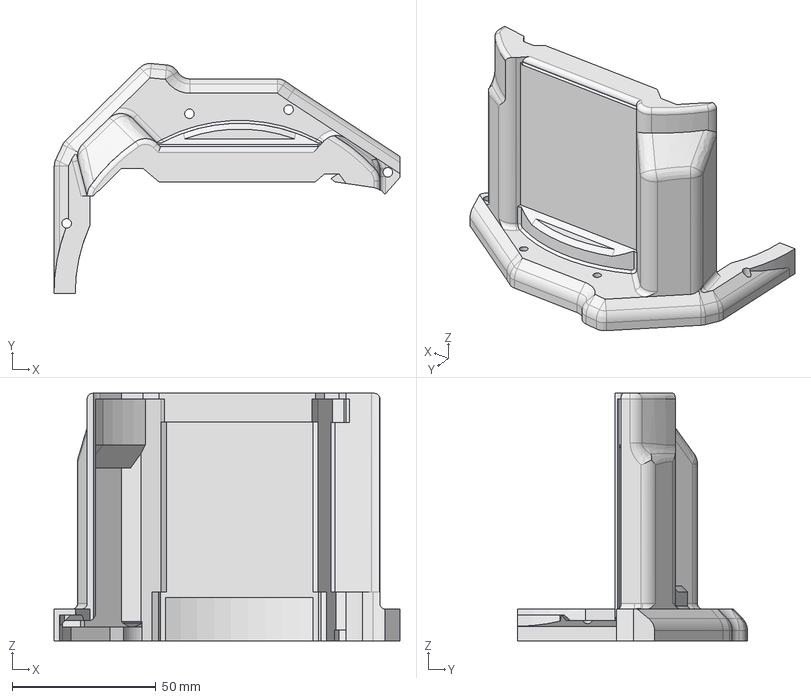
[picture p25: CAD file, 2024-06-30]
cad/v4/STEP_FILES/separator_left.stp
120.2 x 79.9 x 86.0 mm

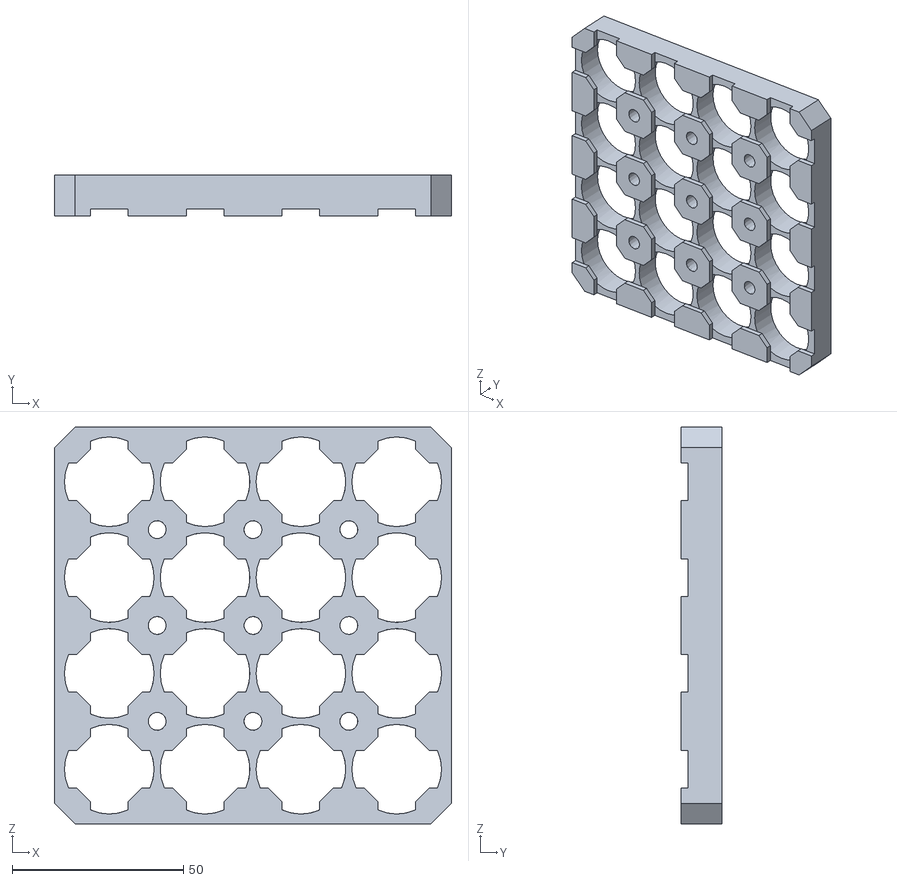
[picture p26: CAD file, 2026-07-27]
cad/v5h/inventor/3Dprints/battery_pack_16s.stl
116.0 x 12.0 x 116.0

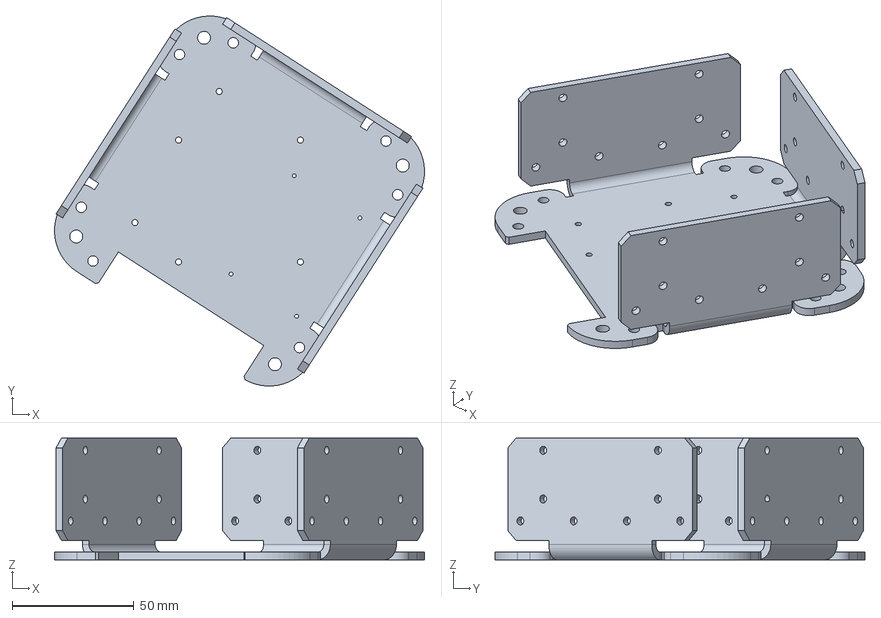
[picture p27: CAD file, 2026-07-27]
cad/v5h/inventor/CNC/mcthermal_plate.stp
151.9 x 151.9 x 50.0 mm

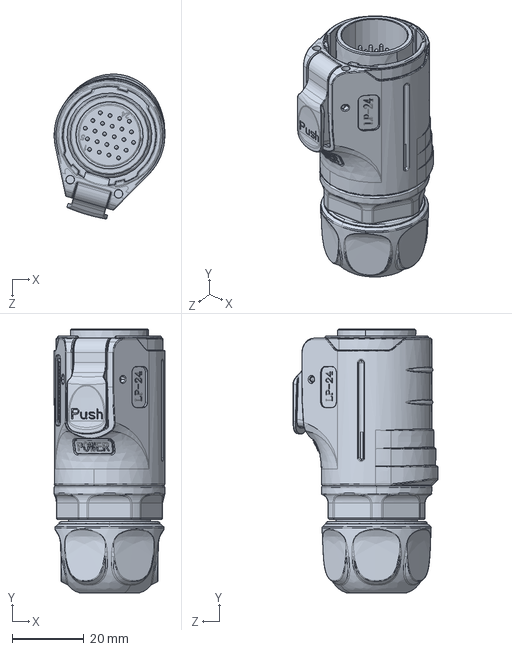
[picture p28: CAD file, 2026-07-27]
cad/v5h/inventor/cnlinko_male_plug.STEP
30.8 x 73.4 x 40.3 mm

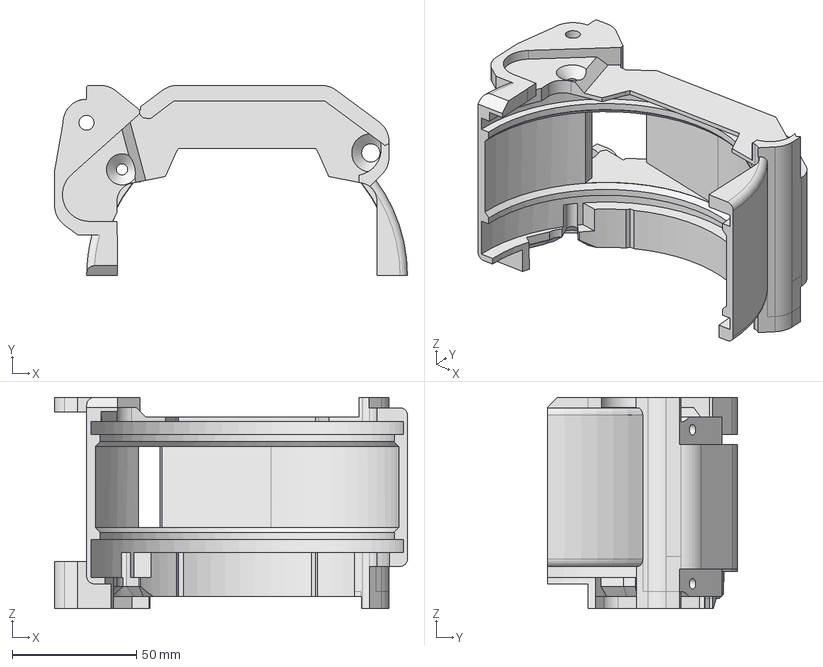
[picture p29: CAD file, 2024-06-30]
cad/v4/STEP_FILES/separator_bottom_mid_bk.stp
141.9 x 76.5 x 85.0 mm

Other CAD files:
firmware/v5h/esp32s3_lillygo_amoled/dimensions/T4-S3-AMOLED.DWG
firmware/v5l/esp32s3_lillygo_amoled/dimensions/T-Display-S3-AMOLED-Touch.DWG
firmware/v5h/esp32s3_lillygo_amoled/dimensions/T-Display-AMOLED-Lite.DWG
firmware/v5l/esp32s3_lillygo_amoled/dimensions/T4-S3-AMOLED.DWG
cad/accessories/paddleboard_end.ipt
cad/accessories/row_wheel_holder_rear.ipt
cad/bearings/OldVersions/bearing_22x8x7.0001.ipt
cad/v4/OldVersions/drivetrain.0022.iam
cad/v4/OldVersions/full_assembly.0067.iam
cad/v4/STEP_FILES/arm_head.stp
cad/v4/STEP_FILES/arm_head_back.stp
cad/v4/STEP_FILES/arm_head_top.stp
cad/v4/STEP_FILES/battery_cover_left.stp
cad/v4/STEP_FILES/battery_cover_right.stp
cad/v4/STEP_FILES/battery_mnt_left.stp
cad/v4/STEP_FILES/battery_mnt_right.stp
cad/v4/STEP_FILES/control_knob_cover.stp
cad/v4/STEP_FILES/drivetrain.stp
cad/v4/STEP_FILES/frame_rring0.stp
cad/v4/STEP_FILES/frame_rring1.stp
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

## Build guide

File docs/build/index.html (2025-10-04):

Skip to content

Open Workout System API

Contents:

- API Reference

Back to top

View this page (https://github.com/openworkoutsystem/digital_weight_device/blob/main/docs/index.rst?plain=true)

Edit this page (https://github.com/openworkoutsystem/digital_weight_device/edit/main/docs/index.rst)

# Welcome to Open Workout System API Documentation!¶

The Open Workout System provides a digital weight device for precise weight measurements in fitness and research applications.

This documentation covers the firmware APIs for the ESP32-based digital weight device.

Contents:

- API Reference
  - Base URL
  - GET /weight
  - POST /calibrate

# Indices and tables¶

- Index
- Module Index
- Search Page

Next

API Reference

Copyright © 2025, Aaron

Made with Sphinx (https://www.sphinx-doc.org/) and @pradyunsg (https://pradyunsg.me)'s Furo (https://github.com/pradyunsg/furo)

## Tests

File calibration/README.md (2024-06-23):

# Calibratin sequence for V4 coming soon

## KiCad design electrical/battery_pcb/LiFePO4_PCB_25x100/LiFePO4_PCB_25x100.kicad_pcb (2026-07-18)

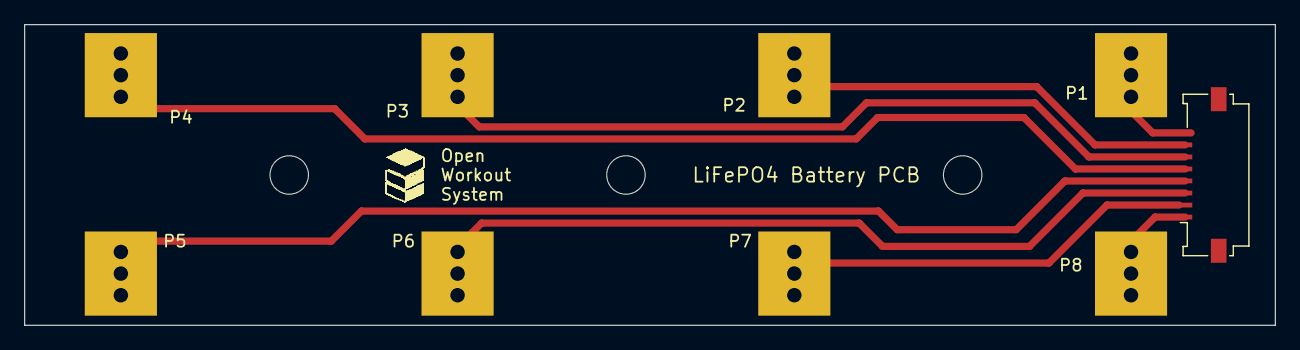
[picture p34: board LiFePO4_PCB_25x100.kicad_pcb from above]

Board: 2 copper layers, 104.0 x 25.0 mm, 8 parts (0 on the bottom side), 8 nets.

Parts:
P1, P2, P3, P4, P5, P6, P7, P8: BattPad; BatteryPad_Edge

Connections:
Net1: P1.1, P1.3, P1.4
Net2: P2.1, P2.2, P2.4
Net3: P3.1, P3.3
Net4: P4.1, P4.4
Net5: P5.1, P5.2, P5.3, P5.4
Net6: P6.1, P6.2, P6.3, P6.4
Net7: P7.1, P7.2, P7.3, P7.4
Net8: P8.1, P8.2, P8.3, P8.4

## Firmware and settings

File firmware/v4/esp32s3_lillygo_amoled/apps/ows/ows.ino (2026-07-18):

/**
 * @file      ows.ino
 * @author    Aaron (aaron@lunarmass.com)
 * @copyright Copyright (c) 2023  Lunar Mass Corp.
 * @date      2023-12-16
 */

#ifdef LILYGO_TWRITSTBAND_S3
#error "Current example does not apply to T-Wristband"
#endif
#include <LilyGo_AMOLED.h>
#include "ows.h"
#include <LV_Helper.h>
#include <Wire.h>

#define SDA_PIN_MCU 43
#define SCL_PIN_MCU 44

#include <Adafruit_seesaw.h>
#define SS_SWITCH_SELECT 1
#define SS_SWITCH_UP 2    // 2
#define SS_SWITCH_LEFT 3  // 3
#define SS_SWITCH_DOWN 4  // 4
#define SS_SWITCH_RIGHT 5 // 5
#define SEESAW_ADDR 0x49
Adafruit_seesaw ss;
int32_t encoder_position;
int32_t encoder_diff_position;

LilyGo_Class amoled;
lv_obj_t *label;

TwoWire Wire_main_mcu = TwoWire(1); // Create a new TwoWire instance. The parameter (1) is optional and depends on the hardware.

#define I2C_SLAVE_ADDRESS 0x08

enum I2C_CommandID
{
    CMD_GET_STATUS = 0x0000,
    CMD_SET_STRENGTH = 0x0001,
    CMD_GET_STRENGTH_LIVE = 0x0002,
    // ... more command IDs
    CMD_SET_DEBUG = 0x0010,
};

struct I2C_CMDID
{
    uint16_t cmd_id;
};

struct SharedStateData
{
    float voltage;
    float current;
    bool newData; // Flag to indicate new data is available
};
SharedStateData sharedStateData;

struct I2C_SET_DEBUG
{
    uint16_t mask = 0; // one-hot mask to indicate which data is new to be set. ignore if 0.
    uint8_t mode = 0;
    uint8_t level = 0;
    bool toggle_switch = false;
};
I2C_SET_DEBUG i2c_set_debug;

// evually see if we can make this a common file with the other mcu
struct I2C_CMD_SET_STRENGTH
{
    uint16_t mask; // one-hot mask to indicate which data is new to be set. ignore if 0.
    float home_linear_position;
    float weight;
    float weight_max;
    float damping_percent;
    bool auto_charge;
    uint8_t dynamic_feedback_mode; // none, chains, vibration, turbulence, bigfish, crank (sharper chains)
    uint8_t dynamic_feedback_amplitude;
};
I2C_CMD_SET_STRENGTH i2c_cmd_set_strength;

// ---------------- UI Event Queue to keep LVGL single-threaded ----------------
enum UiEventType : uint8_t { UIE_KEY = 1, UIE_ROTARY = 2, UIE_BATT = 3 };
struct UiEvent {
    UiEventType type;
    uint32_t    u32;   // keys/rotary value
    float       f32;   // battery voltage if needed
};
static QueueHandle_t uiEventQueue = nullptr;

// --------------- I2C Bus Mutex for Wire_main_mcu (seesaw + main MCU) --------
static SemaphoreHandle_t i2c1Mutex = nullptr;

// --------------- Navigation transition guard (avoid double-trigger) ---------
static volatile uint32_t ui_transition_until_ms = 0; // millis until which nav keys are ignored
static inline bool isTransitionBusy()
{
    // Treat any running animations as busy; also honor our time-based guard window
    return (millis() < ui_transition_until_ms) || (lv_anim_count_running() > 0);
}

// void receiveI2CEvent(int howMany)
// {
//     Serial.println("I2C slave event received.");
//     while (Wire_main_mcu.available())
//     {
//         char c = Wire_main_mcu.read(); // receive byte as a character
//         Serial.print(c);               // print the character
//     }
// }

void setup(void)
{
    Serial.begin(115200);
    // Wire.begin();
    // register events for incoming I2C data from the main MCU
    // Wire_main_mcu.onReceive(receiveI2CEvent);
    Wire_main_mcu.begin(SDA_PIN_MCU, SCL_PIN_MCU, 400000); // faster I2C for encoder/seesaw responsiveness
    Wire_main_mcu.setTimeOut(20);

    // START OF OLED CODE
    bool rslt = false;

    // Enable ultra-fast boot with immediate splash. Optionally set your known board.
    amoled.setFastBoot(true);
    amoled.setSplashFirst(true);
    // If you know your panel, uncomment ONE of these to skip autodetect entirely:
    // amoled.setKnownBoardID(LILYGO_AMOLED_191); // T-Display-S3 AMOLED 1.91"
    // amoled.setKnownBoardID(LILYGO_AMOLED_241); // T4-S3 AMOLED 2.41"

    // Begin LilyGo  1.91 Inch AMOLED board class
    // rslt =  amoled.beginAMOLED_191();

    // Automatically determine the access device
    rslt = amoled.begin();
    // Fast-boot defers touch; initialize it now so LVGL gets touches
    amoled.initTouchNow();
    // Add a small timeout to default Wire as well (LVGL touch / PMU use this)
    Wire.setTimeOut(20);

    if (!rslt)
    {
        while (1)
        {
            Serial.println("The board model cannot be detected, please raise the Core Debug Level to an error");
            delay(1000);
        }
    }

    // Register lvgl helper
    beginLvglHelper(amoled);

    amoled.setHomeButtonCallback([](void *ptr)
                                 {
        Serial.println("Home key pressed!");
        static uint32_t checkMs = 0;
        static uint8_t lastBri = 0;
        if (millis() > checkMs) {
            if (amoled.getBrightness()) {
                lastBri = amoled.getBrightness();
                amoled.setBrightness(0);
            } else {
                amoled.setBrightness(lastBri);
            }
        }
        checkMs = millis() + 200; },
                                 NULL);

    ui_init();

    // Create UI event queue (route all UI updates via main loop)
    uiEventQueue = xQueueCreate(16, sizeof(UiEvent));
    // Create mutex for I2C bus 1 shared by encoder + main MCU
    i2c1Mutex = xSemaphoreCreateMutex();

    // START OF ENCODER CODE
    // while (!Serial)
    //     delay(10);
    Serial.println("Looking for seesaw!");

    // Bind seesaw to the dedicated Wire_main_mcu bus to avoid contention with LVGL/touch on default Wire
    if (!ss.begin(SEESAW_ADDR, -1, &Wire_main_mcu))
    {
        Serial.println("Couldn't find seesaw on default address");
        while (1)
            delay(10);
    }
    Serial.println("seesaw started");
    uint32_t version = ((ss.getVersion() >> 16) & 0xFFFF);
    if (version != 5740)
    {
        Serial.print("Wrong firmware loaded? ");
        Serial.println(version);
        while (1)
            delay(10);
    }
    Serial.println("Found Product 5740");

    ss.pinMode(SS_SWITCH_UP, INPUT_PULLUP);
    ss.pinMode(SS_SWITCH_DOWN, INPUT_PULLUP);
    ss.pinMode(SS_SWITCH_LEFT, INPUT_PULLUP);
    ss.pinMode(SS_SWITCH_RIGHT, INPUT_PULLUP);
    ss.pinMode(SS_SWITCH_SELECT, INPUT_PULLUP);

    // get starting position
    encoder_position = ss.getEncoderPosition();
    encoder_diff_position = 0;

    Serial.println("Turning on interrupts");
    ss.enableEncoderInterrupt();
    ss.setGPIOInterrupts((uint32_t)1 << SS_SWITCH_UP, 1);

    // Create a task for encoder detection
    xTaskCreate(
        encoderTask,   /* Task function. */
        "EncoderTask", /* String with name of task. */
        10000,         /* Stack size in words. */
        NULL,          /* Parameter passed as input of the task */
        3,             /* Higher priority to reduce input lag. */
        NULL);         /* Task handle. */
    // END OF ENCODER CODE

    xTaskCreate(
        readBatteryLifeTask,   /* Task function. */
        "ReadBatteryLifeTask", /* String with name of task. */
        10000,                 /* Stack size in bytes. */
        NULL,                  /* Parameter passed as input to the task. */
        1,                     /* Priority of the task. */
        NULL);                 /* Task handle. */
}

void loop()
{
    // Drain any pending UI events from worker tasks and apply on LVGL thread
    if (uiEventQueue) {
        UiEvent ev;
        // Process multiple events per frame to keep UI snappy
        for (int i = 0; i < 8; ++i) {
            if (xQueueReceive(uiEventQueue, &ev, 0) != pdTRUE) break;
            switch (ev.type) {
                case UIE_KEY:
                    if (ev.u32 == LV_KEY_LEFT || ev.u32 == LV_KEY_RIGHT) {
                        if (!isTransitionBusy()) {
                            dispatchKeyEvent(ev.u32);
                            // Small guard to avoid overlapping screen transitions
                            ui_transition_until_ms = millis() + 220;
                        }
                        // If busy, drop the key; the user can press again after transition
                    } else {
                        dispatchKeyEvent(ev.u32);
                    }
                    break;
                case UIE_ROTARY:
                    // Avoid heavy UI updates during transitions
                    if (!isTransitionBusy()) {
                        dispatchRotaryEvent(ev.u32);
                    }
                    break;
                case UIE_BATT:
                    lv_label_set_text_fmt(ui_LabelBatteryLife,  "%.1fV", ev.f32);
                    lv_label_set_text_fmt(ui_LabelBatteryLife2, "%.1fV", ev.f32);
                    lv_label_set_text_fmt(ui_LabelBatteryLife3, "%.1fV", ev.f32);
                    break;
                default:
                    break;
            }
        }
    }
    lv_task_handler();
    delay(5);
}

void encoderTask(void *parameter)
{
    static uint32_t checkMs = 0;
    const unsigned long debounceTime = 150; // 50 milliseconds
    while (1)
    {
        if (millis() > checkMs)
        {
            if (i2c1Mutex && xSemaphoreTake(i2c1Mutex, pdMS_TO_TICKS(20)) == pdTRUE) {
            if (!ss.digitalRead(SS_SWITCH_UP))
            {
                Serial.println("UP pressed!");
                if (uiEventQueue) { UiEvent ev{UIE_KEY, LV_KEY_UP, 0}; xQueueSend(uiEventQueue, &ev, 0); }
                checkMs = millis() + debounceTime;
            }
            if (!ss.digitalRead(SS_SWITCH_DOWN))
            {
                Serial.println("DOWN pressed!");
                if (uiEventQueue) { UiEvent ev{UIE_KEY, LV_KEY_DOWN, 0}; xQueueSend(uiEventQueue, &ev, 0); }
                checkMs = millis() + debounceTime;
            }
            if (!ss.digitalRead(SS_SWITCH_LEFT))
            {
                Serial.println("LEFT pressed!");
                if (uiEventQueue) { UiEvent ev{UIE_KEY, LV_KEY_LEFT, 0}; xQueueSend(uiEventQueue, &ev, 0); }
                checkMs = millis() + debounceTime;
            }
            if (!ss.digitalRead(SS_SWITCH_RIGHT))
            {
                Serial.println("RIGHT pressed!");
                if (uiEventQueue) { UiEvent ev{UIE_KEY, LV_KEY_RIGHT, 0}; xQueueSend(uiEventQueue, &ev, 0); }
                checkMs = millis() + debounceTime;
            }
            if (!ss.digitalRead(SS_SWITCH_SELECT))
            {
                Serial.println("SELECT pressed!");
                if (uiEventQueue) { UiEvent ev{UIE_KEY, LV_KEY_ENTER, 0}; xQueueSend(uiEventQueue, &ev, 0); }
                checkMs = millis() + debounceTime;
            }
            xSemaphoreGive(i2c1Mutex);
            }
        }

        int32_t new_position = 0;
        if (i2c1Mutex && xSemaphoreTake(i2c1Mutex, pdMS_TO_TICKS(20)) == pdTRUE) {
            new_position = ss.getEncoderPosition();
            xSemaphoreGive(i2c1Mutex);
        } else {
            // If mutex timed out, skip this iteration to avoid bus contention
            vTaskDelay(5 / portTICK_PERIOD_MS);
            continue;
        }
        int32_t new_diff_position = new_position - encoder_position;
        if (encoder_diff_position != new_diff_position)
        {
            Serial.println(new_position);                                                      // display new position
            encoder_position = encoder_position + (new_diff_position - encoder_diff_position); // and save for next round
            // set min and max values
            if (encoder_position < 1)
                encoder_position = 1;
            if (encoder_position > 150)
                encoder_position = 150;
            // ss.setEncoderPosition(encoder_position); // and set it
            encoder_diff_position = new_position - encoder_position;

            // Route rotary change to UI thread
            if (uiEventQueue) { UiEvent ev{UIE_ROTARY, (uint32_t)encoder_position, 0}; xQueueSend(uiEventQueue, &ev, 0); }
        }

        vTaskDelay(5 / portTICK_PERIOD_MS); // modest polling to reduce I2C bus pressure
    }
}

void readBatteryLifeTask(void *parameter)
{
    for (;;) // infinite loop
    {
        // set DATA_LENGTH to the size of the struct
        const size_t DATA_LENGTH = sizeof(sharedStateData);
        if (i2c1Mutex) xSemaphoreTake(i2c1Mutex, portMAX_DELAY);
        Wire_main_mcu.requestFrom(I2C_SLAVE_ADDRESS, DATA_LENGTH);
        // Wait until all data is received
        if (Wire_main_mcu.available() == DATA_LENGTH)
        {
            // Read the data into the sharedStateData struct
            Wire_main_mcu.readBytes((char *)&sharedStateData, DATA_LENGTH);

            // Log & send voltage update to UI thread
            Serial.print("Voltage: ");
            Serial.print(sharedStateData.voltage);
            Serial.print("V, Current: ");
            Serial.print(sharedStateData.current);
            Serial.print("A, New Data: ");
            Serial.println(sharedStateData.newData ? "Yes" : "No");
            if (uiEventQueue) { UiEvent ev{UIE_BATT, 0, sharedStateData.voltage}; xQueueSend(uiEventQueue, &ev, 0); }
        }
        else
        {
            Serial.println("Failed to receive complete data");
        }
        if (i2c1Mutex) xSemaphoreGive(i2c1Mutex);
        vTaskDelay(5000 / portTICK_PERIOD_MS); // delay for 1 second
    }
}

void readBatteryLife()
{
    // Read the battery voltage from GPIO 4 (ADC input)
    uint16_t adcValue = analogRead(4);

    // Convert ADC value to voltage considering the voltage divider and ADC resolution
    float batteryVoltage = (adcValue / 4095.0) * 3.4 * 2; // Multiply by 2 due to voltage divider... 1.1 is the internal reference voltage factor

    // Convert voltage to percentage (4.1V is 100% and 3.6V is 0%)
    float batteryPercent = (batteryVoltage - 3.6) * 100.0 / (4.1 - 3.6);

    // Clamp the percentage to be between 0% and 100%
    if (batteryPercent > 100.0)
    {
        batteryPercent = 100.0;
    }
    else if (batteryPercent < 0.0)
    {
        batteryPercent = 0.0;
    }

    // Update the label with the calculated battery percentage
    lv_label_set_text_fmt(ui_LabelBatteryLife, "%d%%", (int)batteryPercent);
}

void dispatchRotaryEvent(uint32_t value)
{
    lv_obj_t *active_screen = lv_scr_act(); // Get the currently active screen

    // You can use a switch-case or if-else statements to decide based on the active screen
    if (active_screen == ui_StrengthScreen)
    {
        // Call the event handler for the MainScreen
        handleMainScreenEvent(value);
    }
}

void handleMainScreenEvent(uint32_t value)
{
    lv_label_set_text_fmt(ui_WeightValue, "%d", value);

    // Populate the I2C_CMD_SET_STRENGTH struct
    i2c_cmd_set_strength.mask = 0x0002;
    i2c_cmd_set_strength.home_linear_position = 0;
    i2c_cmd_set_strength.weight = value;
    i2c_cmd_set_strength.weight_max = 150; // only value updated here
    i2c_cmd_set_strength.damping_percent = 0;
    i2c_cmd_set_strength.auto_charge = false;
    i2c_cmd_set_strength.dynamic_feedback_mode = 0;
    i2c_cmd_set_strength.dynamic_feedback_amplitude = 0;

    // Send the struct as a data packet
    sendCommand(CMD_SET_STRENGTH, (uint8_t *)&i2c_cmd_set_strength, sizeof(i2c_cmd_set_strength));
}

void dispatchKeyEvent(uint32_t key)
{
    lv_obj_t *active_screen = lv_scr_act(); // Get the currently active screen

    if (active_screen)
    {
        lv_event_send(active_screen, LV_EVENT_KEY, (void *)&key);
    }

    if (active_screen == ui_StrengthScreen && key == LV_KEY_ENTER)
    {
        // Populate the I2C_CMD_SET_STRENGTH struct
        i2c_set_debug.mask = 0x0004; // one-hot mask to indicate which data is new to be set. ignore if 0.
        i2c_set_debug.toggle_switch = true;

        // Send the struct as a data packet
        sendCommand(CMD_SET_DEBUG, (uint8_t *)&i2c_set_debug, sizeof(i2c_set_debug));
    }
}

void sendCommand(I2C_CommandID cmd, const uint8_t *data, size_t dataSize)
{
    // Start I2C transmission
    Wire_main_mcu.beginTransmission(I2C_SLAVE_ADDRESS);

    // Send the command ID
    uint16_t cmdID = static_cast<uint16_t>(cmd);
    Wire_main_mcu.write((uint8_t *)&cmdID, sizeof(cmdID));

    // Send the additional data if any
    if (data != nullptr && dataSize > 0)
    {
        Wire_main_mcu.write(data, dataSize);
    }

    // End the transmission
    byte status = Wire_main_mcu.endTransmission();
    if (status != 0)
    {
        Serial.println("I2C slave error");
        Serial.println(status);
    }
}

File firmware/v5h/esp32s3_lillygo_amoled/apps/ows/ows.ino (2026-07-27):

/**
 * @file      ows.ino
 * @author    Aaron (aaron@lunarmass.com)
 * @copyright Copyright (c) 2023  Lunar Mass Corp.
 * @date      2023-12-16
 */

#ifdef LILYGO_TWRITSTBAND_S3
#error "Current example does not apply to T-Wristband"
#endif
#include <LilyGo_AMOLED.h>
#include "ows.h"
#include <LV_Helper.h>
#include <Wire.h>
#include "weight_numpad.h"
#include "ui_input_gate.h"

// Explicit prototypes (keeps the Arduino .ino preprocessor honest)
void weightValueClicked(lv_event_t *e);
void numpadWeightConfirmed(int32_t value);
void setWeightDisplay(int32_t value);
void sendWeightCommand(int32_t value);
void zeroZonePressed(lv_event_t *e);
void createZeroWeightZone(void);
void rowScreenEvent(lv_event_t *e);
void gearValueClicked(lv_event_t *e);
void dragValueClicked(lv_event_t *e);
void numpadGearConfirmed(int32_t value);
void numpadDragConfirmed(int32_t value);
void setRowLabels(void);
void sendRowCommand(bool enable);
void mainMcuFrameReceived(int howMany);
void mainMcuMailboxRequested(void);
void concentricValueClicked(lv_event_t *e);
void numpadConcentricConfirmed(int32_t value);
void setConcentricLabel(void);
void sendConcentricCommand(void);

#define SDA_PIN_MCU 43
#define SCL_PIN_MCU 44

LilyGo_Class amoled;
lv_obj_t *label;

// Current weight setting (was tracked by the external encoder; now set via
// the on-screen numpad). 0 lb = motor idle (device does not move at all);
// 1 lb or more = active strength mode. Defaults to 0 (idle), matching the
// main board's power-on state.
static int32_t currentWeight = 0;
#define WEIGHT_MIN 0
#define WEIGHT_MAX 150

TwoWire Wire_main_mcu = TwoWire(1); // Create a new TwoWire instance. The parameter (1) is optional and depends on the hardware.

#define I2C_SLAVE_ADDRESS 0x08

enum I2C_CommandID
{
    CMD_GET_STATUS = 0x0000,
    CMD_SET_STRENGTH = 0x0001,
    CMD_GET_STRENGTH_LIVE = 0x0002,
    CMD_SET_ROW = 0x0003,
    // ... more command IDs
    CMD_SET_DEBUG = 0x0010,
};

struct I2C_CMDID
{
    uint16_t cmd_id;
};

// NOTE: layout must stay byte-identical with the main board's copy in
// esp32s3_main/include/I2CCommunication.h (read raw over I2C).
struct SharedStateData
{
    float voltage;
    float current;
    bool newData; // Flag to indicate fresh voltage/current data
    // Weight-update gate state from the main board: a commanded weight only
    // takes effect after the user confirms it by pulling; it can cancel.
    float active_weight;    // latched weight currently in effect
    float pending_weight;   // requested value awaiting confirmation
    uint8_t weight_pending; // 1 while a requested value awaits confirmation
    // Row mode: param echoes (0 = row mode off on the main board — used to
    // detect a dropped enable/disable and resend) plus stroke metrics.
    uint8_t row_spm;   // strokes per minute
    uint8_t row_drag;  // applied drag 1-10, 0 while row mode is off
    uint8_t row_gear;  // applied gear 1-10, 0 while row mode is off
    float row_watts;   // smoothed per-stroke average power
    uint32_t ip_addr;  // device IPv4 (octet0 in LSB; 0 = no WiFi)
    // Integrity trailer:
    uint8_t seq;      // incremented per response by the main board
    uint8_t checksum; // additive checksum (seed 0xA5) over preceding bytes
};
SharedStateData sharedStateData;

// ROLE FLIP (2026-07-13): the C5 masters this link — its Arduino I2C slave
// driver never ACKs on that silicon, while THIS board's S3 slave role is
// the exact combination the old main board ran for months. The C5 pushes
// the 32-byte status frame at 10 Hz (mainMcuFrameReceived) and polls this
// command mailbox (mainMcuMailboxRequested); commands are staged by
// sendCommand and held until replaced — the C5 dedups by seq, so lost
// polls retry free. Layout must stay byte-identical with the C5's copy in
// esp32c5_seed_studio_main/include/I2CCommunication.h.
// NOTE: this type must be defined ABOVE the first function definition in
// this file — the .ino preprocessor hoists generated prototypes there.
struct I2C_CMD_MAILBOX
{
    uint8_t has_cmd;     // 0 = empty mailbox
    uint8_t seq;         // increments per NEW command from this screen
    uint16_t cmdid;      // I2C_CommandID
    uint8_t payload[26]; // command struct (largest: I2C_CMD_SET_STRENGTH, 24)
    uint8_t reserved;
    uint8_t checksum;    // additive, seed 0xA5, over all preceding bytes
};                       // sizeof = 32

static I2C_CMD_MAILBOX g_mailbox = {};
// Latest status frame pushed by the C5, consumed by readBatteryLifeTask
static SharedStateData g_rxFrame;
static volatile bool g_rxFresh = false;
static volatile uint32_t g_rxMs = 0;
static portMUX_TYPE g_linkMux = portMUX_INITIALIZER_UNLOCKED;

static uint8_t sharedStateChecksum(const SharedStateData *d)
{
    const uint8_t *p = (const uint8_t *)d;
    uint8_t sum = 0xA5;
    for (size_t i = 0; i < offsetof(SharedStateData, checksum); i++)
    {
        sum += p[i];
    }
    return sum;
}

// Suppress display re-sync briefly after we send a weight, so a stale status
// poll can't snap the label back before the main board registers the command.
static uint32_t lastWeightSentMs = 0;
// Command acknowledgment: a sent weight stays "unacked" until a status poll
// shows the main board acting on it (armed as pending, or applied as
// active). Unacked commands are resent — a dropped I2C write must not let
// the display sync snap the value back as if the user never set it.
static bool weightAckPending = false;
static uint8_t weightSendTries = 0;

struct I2C_SET_DEBUG
{
    uint16_t mask = 0; // one-hot mask to indicate which data is new to be set. ignore if 0.
    uint8_t mode = 0;
    uint8_t level = 0;
    bool toggle_switch = false;
};
I2C_SET_DEBUG i2c_set_debug;

// evually see if we can make this a common file with the other mcu
struct I2C_CMD_SET_STRENGTH
{
    uint16_t mask; // one-hot mask to indicate which data is new to be set. ignore if 0.
    float home_linear_position;
    float weight;
    float weight_max;
    float concentric_pct; // mask 0x0008: 0-100 concentric-only unloading
                          // (was damping_percent — same offset/size)
    bool auto_charge;
    uint8_t dynamic_feedback_mode; // none, chains, vibration, turbulence, bigfish, crank (sharper chains)
    uint8_t dynamic_feedback_amplitude;
};
I2C_CMD_SET_STRENGTH i2c_cmd_set_strength;

// NOTE: layout must stay byte-identical with the main board's copy in
// esp32c5_seed_studio_main/include/I2CCommunication.h.
struct I2C_CMD_SET_ROW
{
    uint16_t mask;      // 0x0001 = gear, 0x0002 = drag, 0x0004 = row_enable
    uint8_t gear;       // 1-10
    uint8_t drag;       // 1-10
    uint8_t row_enable; // with mask 0x0004: 1 = row mode on, 0 = off
};
I2C_CMD_SET_ROW i2c_cmd_set_row;

static uint8_t mailboxChecksum(const I2C_CMD_MAILBOX *mb)
{
    const uint8_t *p = (const uint8_t *)mb;
    uint8_t sum = 0xA5;
    for (size_t i = 0; i < offsetof(I2C_CMD_MAILBOX, checksum); i++)
    {
        sum += p[i];
    }
    return sum;
}
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

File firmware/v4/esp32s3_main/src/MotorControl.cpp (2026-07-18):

#include "MotorControl.h"
#include "ErrorHandling.h"
#include "CANCommunication.h"
#include "I2CCommunication.h"
#include "SharedData.h" // Include the shared data header
#include <math.h>

ControlFeedback controlFeedback; // Define the controlFeedback structure

// declare functions
float applyForceControl(float target_force, float position);
float applyDetentControl(float target_force, float position);
float applyPulseControl(float target_force);
float applyRowModeControl(float target_force, float velocity, float &row_force_strength);

void initMotorControl()
{
    xTaskCreatePinnedToCore(
        MotorControlTask,   // Task function
        "MotorControlTask", // Name of the task
        10000,              // Stack size in words
        NULL,               // Task input parameter
        2,                  // Priority of the task (equal to WS for round-robin)
        NULL,               // Task handle
        0);                 // Core where the task should run
}

void MotorControlTask(void *parameter)
{
    int counter = 0;
    int lastID = 0;
    static uint8_t lastAppliedMode = 255; // Track last mode to avoid redundant CAN sends

    struct timeval tv_now;
    gettimeofday(&tv_now, NULL);
    int64_t time_us = (int64_t)tv_now.tv_sec * 1000000L + (int64_t)tv_now.tv_usec;
    int64_t prev_time_us = time_us;
    int64_t runInterval_us = 2000; // 500Hz loop time.

    float m1_torque_soft = 0;
    float m2_torque_soft = 0;
    float min_torque_m1 = -0.4;
    float m1_torque_soft_max = 0;
    float m1_torque_soft_min = 0;
    float m2_torque_soft_max = 0;
    float m2_torque_soft_min = 0;

    int torque_matrix_a = 0;
    int torque_matrix_b = 1;
    float torque_interpolation = 0;
    float m1_minus_torque_soft_fn = 0;
    float m1_minus_torque_soft_fm = 0;
    float m1_plus_torque_soft_fn = 0;
    float m1_plus_torque_soft_fm = 0;
    float m2_minus_torque_soft_fn = 0;
    float m2_minus_torque_soft_fm = 0;
    float m2_plus_torque_soft_fn = 0;
    float m2_plus_torque_soft_fm = 0;
    float velocity_delta = 0;

    float vel_factor = 0.5;
    float vel_minus_factor = 0.5;
    float vel_plus_factor = 0.5;

    float m1_velocity = -20;
    float m2_velocity = -20;

    float row_force_strength = 0;
    static bool modesConfigured = false; // Configure controller/input modes once

    // a 5x10 matrix to store the torque values for m1 and m2 for each range of strength mode. 5 rows and 10 columns
    // header are force, velocity_delta, -M1_Fn, -M1_Fm, M1_Fn, M1_Fm, -M2_Fn, -M2_Fm, M2_Fn, M2_Fm
    // minus sign indicates the direction of motion of the motor is towrds the device and positive sign indicates the direction of motion of the motor is away from the device towards the user
    // Fn is the static force value and Fm is the velocity coeficient force... such that F = Fn + Fm * v
    float torque_matrix[5][10] = {
        {9.8, 1, -0.7, 0, -0.5, 0, 0.2, 0, 0.2, 0.5}, // 1 lb
        {50, 1, -0.95, 0, -0.8, 0, 0.2, 0, 0.2, 0.5}, // 5 lb
        {200, 1, -1.3, 0, -1, 0, 0, 0, 0, 0},         // 10 lb
        {640, 1, -0.6, 0, -0.6, 0, -0.6, 0, -0.4, 0}, // 16 lb
        {2000, 1, -0.6, 0, -0.6, 0, -6, 0, -5, 0.1}   // 150 lb
    };

    sendMotorRX(CAN_NODEID_M2, TORQUE_SOFT_MIN_M2, (float)-1);

    // init force modulation params
    updateForceData("constant", 100, 30, 0.5, 2); // off, constant, linear
    updateDetentData("off", 50, .2, .3, 10);
    updatePulseData("off", 0, 100, 16);
    updateRowData("off", 20, 3, 0);

    while (true)
    {
        gettimeofday(&tv_now, NULL);
        time_us = (int64_t)tv_now.tv_sec * 1000000L + (int64_t)tv_now.tv_usec;
        int64_t elapsed_us = time_us - prev_time_us;
        if (elapsed_us < runInterval_us)
        {
            // Yield to avoid spin-wait starvation; sleep fractional ms if possible
            int64_t remaining_us = runInterval_us - elapsed_us;
            if (remaining_us > 1000) {
                vTaskDelay(pdMS_TO_TICKS(1)); // yield ~1ms
            } else {
                taskYIELD(); // yield immediately for sub-ms waits
            }
            continue;
        }
        prev_time_us = time_us;

        // Drain command queue from WS/HTTP without blocking (before timing gate)
        // Coalesce to the latest requested state to avoid rapid back-to-back toggles causing traffic bursts
        CommandMsg msg;
        CommandType desiredType = CMD_NONE;
        float desiredWeightKg = 0.0f;
        unsigned long desiredCmdMs = 0;
        while (g_cmdQueue && xQueueReceive(g_cmdQueue, &msg, 0) == pdTRUE) {
            desiredType = msg.type;
            desiredWeightKg = msg.weight_kg;
            desiredCmdMs = millis();
        }
        if (desiredType != CMD_NONE) {
            if (xSemaphoreTake(mutex, 0) == pdTRUE) {
                if (desiredType == CMD_STRENGTH) {
                    sharedCfgData.target_force = desiredWeightKg * 9.81f;
                    if (controlState.mode != 1) {
                        controlState.mode = 1;
                        pendingApplyStrength = true;
                    }
                } else if (desiredType == CMD_IDLE) {
                    if (controlState.mode != 0) {
                        controlState.mode = 0;
                        pendingApplyIdle = true;
                    }
                }
                xSemaphoreGive(mutex);
            }
            sharedData.t_cmd_set_ms = desiredCmdMs;
        }
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

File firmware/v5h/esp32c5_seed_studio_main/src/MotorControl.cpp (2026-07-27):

#include "MotorControl.h"
#include "ErrorHandling.h"
#include "CANCommunication.h"
#include "I2CCommunication.h"
#include "Logging.h"
#include "SharedData.h" // Include the shared data header
#include <math.h>

ControlFeedback controlFeedback; // Define the controlFeedback structure

// declare functions — force-profile positions are REVS FROM THE DOCK
// (dHome), not raw encoder position, so profiles repeat identically every
// rep and survive home re-establishment across sessions
float applyForceControl(float target_force, float dHome);
float applyDetentControl(float target_force, float dHome);
float applyPulseControl(float target_force);

// ========================= moteus transport notes ===========================
// Force rendering keeps the ODrive-era architecture: the axis chases an
// unreachable reel-in velocity while a live torque cap IS the rendered
// force. On moteus that is ONE frame per control tick — position mode with
// position=NaN (target re-anchors at the current output every frame),
// velocity = the zone-limited reel-in setpoint, maximum_torque = the cap —
// plus a query bit so the reply carries position/velocity/torque back.
// There is no pre-staging choreography like the ODrive needed: the same
// frame that (re)enters position mode carries the torque bound, so the axis
// can never engage on a stale limit.
//
// Differences vs the ODrive setup, called out for bring-up:
// - The moteus per-command torque cap is SYMMETRIC (±). The ODrive's tiny
//   separate push-toward-user bound (torque_soft_max ~1 lbf) has no direct
//   equivalent; braking of a fast inrushing strap is instead bounded by the
//   drop-catch shed, which collapses the cap to the recoil floor within one
//   control cycle of a fast reel-in. Watch this on the bench.
// - Position units are output REVOLUTIONS (== ODrive motor turns on this
//   near-direct drivetrain), velocity rev/s, torque Nm — values carry over.
// - Feedback is query-driven at the control tick rate instead of the
//   ODrive's 100 Hz broadcast, so the force pipeline now runs every tick.
// - servo.default_timeout_s is left at the moteus config default: if this
//   stream ever stalls, the axis drops to its timeout mode (configure
//   "stopped" via moteus_tool) — strap goes slack, which is the safe way
//   for this machine to fail.
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

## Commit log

2024-06-22 initial release
    [BOM.xlsx, T-Display-AMOLED-Lite.DWG, T-Display-S3-AMOLED-Touch.DWG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]
2024-06-22 first cad upload
    [100kv_motor.0004.iam, 100kv_motor.iam, 100kv_motor.ipt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]
2024-06-22 new cad images
2024-06-23 feat: Generate Bill of Materials (BOM) markdown file
    [BOM.csv, BOM.xlsx]
2024-06-23 refactor: Update BOM item numbering logic
    [BOM.csv]
2024-06-23 feat: Add V4 BOM link to README
2024-06-23 feat: Update README with V4 BOM link
2024-06-23 folder restructure
    [T-Display-AMOLED-Lite.DWG, T-Display-S3-AMOLED-Touch.DWG, T4-S3-AMOLED.DWG]
2024-06-24 feat: Add motor data CSV and stats markdown files
    [motor_data.csv]
2024-06-24 Update motor spool radius in motor_design.py
2024-06-25 Update motor spool radius and gear ratio in motor_design.py
    [motor_data.csv]
2024-06-28 Update motor_data.csv with corrected weight for Cube Mars RO100 Frameless kv55 motor
    [motor_data.csv]
2024-06-28 Update motor weight to 750 grams
2024-06-30 added step files
    [arm_head.stp, arm_head_back.stp, arm_head_top.stp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]
2026-07-18 big push
    [LiFePO4_PCB_25x100.kicad_pcb, LiFePO4_PCB_25x100.kicad_sch, T-Display-AMOLED-Lite.DWG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]
2026-07-18 Update recoil torque and enhance WiFi connection handling
2026-07-27 cad update
    [0-00.ipt, 0-00_10_14.ipt, 0-00_5_4.ipt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]
